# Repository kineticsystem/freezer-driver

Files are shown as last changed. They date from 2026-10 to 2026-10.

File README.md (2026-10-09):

# StepIt Freezer







## Table of Contents <!-- omit in toc -->

- [Introduction](#introduction)
- [Prerequisites](#prerequisites)
- [Install StepIt Freezer on the Microcontroller](#install-stepit-freezer-on-the-microcontroller)
  - [Connect the Arduino Nano](#connect-the-arduino-nano)
  - [Access the Serial Port](#access-the-serial-port)
  - [Flash the Firmware](#flash-the-firmware)
- [Install StepIt Freezer on the Local Computer](#install-stepit-freezer-on-the-local-computer)
  - [Check out the Submodules](#check-out-the-submodules)
  - [Pre-Commit Hooks](#pre-commit-hooks)
  - [Build the Project](#build-the-project)
- [Running the Application](#running-the-application)
  - [The Board Page](#the-board-page)
  - [Parameters](#parameters)
- [Troubleshooting](#troubleshooting)
- [How to run GitHub Actions locally](#how-to-run-github-actions-locally)

## Introduction

StepIt Freezer is a project to fire cameras and flashes from ROS2, through the Freezer board: an Arduino Nano driving two 74HC595 shift registers and 16 optocouplers, wired to 8 output jacks and 1 input jack.

- Fire up to 7 cameras and a flash at the same time, with the timing of each step kept by a hardware timer of the Nano.
- Load a sequence of steps once, each an output pattern and a hold time, and fire it with one short command, or with the remote trigger on IN1.
- Switch outputs on and off outside a shot, e.g. the lights, and stop a shot at any time.
- Watch the board in a web page: its outputs live, the commands, and the timing of every shot, against a fake controller or the real board.
- Talk to the Nano with a framed, CRC-checked protocol of one request and one response.

> [!WARNING]
> The project is being built. How it is built, and why, is in [ARCHITECTURE.md](docs/ARCHITECTURE.md); the ideas we weighed on the way are in [Brainstorming.md](Brainstorming.md). The firmware and the ROS2 side fire shots, tested on a Nano on its own; they have not yet driven cameras through the Freezer board.

## Prerequisites

To run StepIt Freezer, we need a computer with Ubuntu 24.04 and ROS2 Jazzy. Please refer to the document [Install ROS2 Jazzy on Ubuntu](https://docs.ros.org/en/jazzy/Installation/Ubuntu-Install-Debs.html).

StepIt Freezer runs with a fake controller by default, so we do not need the board to try it. For a real application, we need the following hardware.

- 1 x Freezer board, see its circuit, PCB and Gerber files in [docs/hardware](docs/hardware/README.md).
- 1 x [Arduino Nano 3.0](https://docs.arduino.cc/hardware/nano/), with the FTDI FT232R USB chip.
- 1 x USB cable, mini-B, that carries data, not only power.

## Install StepIt Freezer on the Microcontroller

This step is only required if you use a real hardware.

### Connect the Arduino Nano

Connect the Nano to the computer and check that Linux sees it. Run the following command, then plug the Nano in:

```
journalctl -kf
```

A working connection prints the following lines; the port is the last word, usually `ttyUSB0`.

```
usb 1-9: New USB device found, idVendor=0403, idProduct=6001, bcdDevice= 6.00
usb 1-9: Product: FT232R USB UART
usb 1-9: FTDI USB Serial Device converter now attached to ttyUSB0
```

If nothing is printed at all, see [Troubleshooting](#troubleshooting).

### Access the Serial Port

The port `/dev/ttyUSB0` belongs to the group `dialout`. To read and write it, without being root, you must add your user to that group:

```
sudo usermod -aG dialout $USER
```

The new group applies after we log out and log in again. To use the port straight away in the current session, grant our user access to it. The grant lasts until the Nano is unplugged.

```
sudo setfacl -m u:$USER:rw /dev/ttyUSB0
```

> [!IMPORTANT]
> A Nano clone with a CH340 USB chip, `idVendor=1a86`, is taken by `brltty`, the service for braille displays: its port appears and disappears at once. If you do not use a braille display, remove it with `sudo apt remove brltty`. A Nano with an FTDI chip is not affected.

No udev rule is required: the Nano is programmed over its serial port, which the group `dialout` already covers.

### Flash the Firmware

We develop the firmware with Visual Studio Code and the [PlatformIO](https://platformio.org) extension. Installing the Arduino IDE is not required.

The firmware, version 2.0.0, answers `Info`, `Echo`, `LoadSequence`, `Shoot`, `Status`, `SetOutputs` and `Stop`, and fires the loaded sequence when IN1 is pressed, unless a shot is running or no sequence is loaded. Timer1 runs the shot: each step starts at its own time, within about 5 µs, measured on the Nano. A step must last at least 40 µs: shorter steps fall behind, one after the other. The driver refuses a firmware of another major version, e.g. 1.1.0: flash the firmware of the same workspace.

To flash the microcontroller code into the Nano:

- Open VSCode
- Install the extension PlatformIO
- Open the subfolder `src/freezer_mcu` in VSCode
- Select the correct device and flash it

The same can be done from a terminal:

```
cd src/freezer_mcu
pio run --target upload --upload-port /dev/ttyUSB0
```

The project targets the board `nanoatmega328`, a Nano with the old bootloader, which listens at 57600 baud. A Nano with the newer Optiboot bootloader listens at 115200 baud: the upload then fails with `not in sync`, and the board in [`platformio.ini`](src/freezer_mcu/platformio.ini) must be `nanoatmega328new`.

The Nano resets every time the port is opened, and the firmware answers only once the bootloader has given up waiting for an upload: about 0.65 s on our Nano. StepIt Freezer waits for it, see `connect_delay` in [Brainstorming.md](Brainstorming.md).

Before the first upload to a Nano, save the firmware it already has, so that it can be written back. The folder `backup` is ignored by git: each machine keeps its own.

```
mkdir -p backup
avrdude -p atmega328p -c arduino -P /dev/ttyUSB0 -b 57600 -U flash:r:backup/nano-flash.hex:i -U eeprom:r:backup/nano-eeprom.hex:i
```

To write it back:

```
avrdude -p atmega328p -c arduino -P /dev/ttyUSB0 -b 57600 -U flash:w:backup/nano-flash.hex:i -U eeprom:w:backup/nano-eeprom.hex:i
```

PlatformIO installs `avrdude` in `~/.platformio/packages/tool-avrdude`; call it from there, with `-C ~/.platformio/packages/tool-avrdude/avrdude.conf`, if it is not on the `PATH`.

## Install StepIt Freezer on the Local Computer

### Check out the Submodules

The packages `framed_serial` and `serial` are git submodules, in `modules/framed-serial` and `modules/serial`. Clone the repository with its submodules:

```
git clone --recurse-submodules git@github.com:kineticsystem/stepit-freezer.git
```

If you missed the switch `--recurse-submodules`, fetch them with the following command:

```
git submodule update --init --recursive
```

Remember to enable recursion for relevant git commands, such that regular commands recurse into submodules by default.

```
git config --global submodule.recurse true
```

### Pre-Commit Hooks

Install the git pre-commit hooks, which format and check the code at every commit, with the following command:

```
pre-commit install
```

### Build the Project

The preferred way to build and run StepIt Freezer is to use a Docker container. It is defined in [`docker/docker-compose.yml`](docker/docker-compose.yml) and driven by the [`docker/dock.sh`](docker/dock.sh) script. See [docker/README.md](docker/README.md) for more details.

> [!IMPORTANT]
> The docker container provides a default user `developer` with password `developer`. That user may run `sudo` without being asked for it, so that the scripts in `bin` also work from a non-interactive shell, e.g.
> `docker exec stepit-freezer update.sh`.

Build the image and create the container. The script always mounts the repo it belongs to, so it can be called from anywhere:

```
./docker/dock.sh stepit-freezer build
```

Start the container with an interactive shell:

```
./docker/dock.sh stepit-freezer start
```

The container is privileged and mounts `/dev`, so the Nano on `/dev/ttyUSB0` is reachable from inside it. The commands below assume you are inside the container.

Install all required dependencies, including the packages of the board page.

```
update
```

Run Colcon to build the project, then build the board page into `web/dist`.

```
build
```

Execute all tests, those of the board page first.

```
test
```

The packages are the following.

| Package | Role |
|---|---|
| `freezer_msgs` | the `Shoot` action, the `Step`, `Outputs` and `Shot` messages, and the `SetOutputs` service |
| `freezer_driver` | the `Driver` interface, `DefaultDriver` over the serial port, `FakeDriver`, the sequence rules, the recipes, and `ShotRunner`, which runs one shot on a driver |
| `freezer_node` | the node `freezer`: the `Shoot` action server, the services `set_outputs` and `stop`, the topics `outputs` and `shots`, its parameters and its launch file |
| `framed_serial` | the framed serial protocol, in the submodule `modules/framed-serial`, from [framed-serial](https://github.com/kineticsystem/framed-serial) |
| `serial` | the serial port library, in the submodule `modules/serial`, from [serial](https://github.com/kineticsystem/serial), branch `ros2` |
| `freezer_mcu` | the PlatformIO project of the Nano, in `src/freezer_mcu`, not built by colcon |
| `web` | the board page, in React and TypeScript, built with Vite and pnpm, not built by colcon |

## Running the Application

By default, the node runs with a fake controller, so we do not need the board. Run the following commands to start StepIt Freezer:

```
source ~/ws/install/setup.bash
ros2 launch freezer_node freezer.launch.py
```

Open a different terminal, attach to the same container with `./docker/dock.sh stepit-freezer start`, and fire the default sequence:

```
ros2 action send_goal --feedback /freezer/shoot freezer_msgs/action/Shoot "{}"
```

The feedback says `state: 0` while the sequence is loaded into the controller, then `state: 1` with the shot id once the shot has started. The result comes when the controller reports the shot has ended, with the shot id and the time it started. A client can miss the first feedback: ROS2 drops the feedback published before the client has processed the acceptance of its goal. A client that needs to know a shot has started can rely on the result, not on the feedback.

To fire a sequence by name, give it in the goal:

```
ros2 action send_goal /freezer/shoot freezer_msgs/action/Shoot "{sequence: timed_light}"
```

To fire a raw table, for experiments, give its steps. Each step is a pattern of the 16 outputs and how long to hold it, in µs; the last step must switch every output off. This one focuses and opens the shutter of the camera on OUT1 for 100 ms:

```
ros2 action send_goal /freezer/shoot freezer_msgs/action/Shoot "{steps: [{outputs: 2, hold_us: 100000}, {outputs: 3, hold_us: 100000}, {outputs: 0, hold_us: 200000}]}"
```

A goal is rejected when no controller is connected, when a shot is running, or when its sequence breaks a rule of the controller. A rejection carries no reason in ROS2: the node logs it.

To switch outputs on outside a shot, e.g. lights on OUT8, give their pattern; they stay on until the next pattern, a shot, or a stop. A shot owns every output: while it runs, the outputs cannot be set, and it ends with every output off, lights included.

```
ros2 service call /freezer/set_outputs freezer_msgs/srv/SetOutputs "{outputs: 49152}"
ros2 service call /freezer/set_outputs freezer_msgs/srv/SetOutputs "{outputs: 0}"
```

To stop a shot where it is, and switch every output off, call `stop`. The goal of the shot aborts with the message `Stopped.`.

```
ros2 service call /freezer/stop std_srvs/srv/Trigger
```

Pressing the remote trigger, on IN1, fires the sequence loaded last, without the node; nothing is fired before the node has loaded one. A goal sent while that shot runs aborts: the controller is busy. The node sees that shot by polling the controller while it is idle, and tells it on `~/shots` like its own. With the fake controller, a service presses IN1:

```
ros2 service call /freezer/fake/press_trigger std_srvs/srv/Trigger
```

The node tells what the board does on two topics, which keep their last message for a client that subscribes late: `~/outputs`, the pattern of the outputs whenever it changes, and `~/shots`, each shot when it starts, with its steps, and when it ends.

```
ros2 topic echo /freezer/outputs
ros2 topic echo /freezer/shots
```

A third topic, `~/status`, tells whether the node talks to the controller, and why not, e.g. `No Freezer controller.`. It keeps its last message too, and comes again every second, so that a client knows the node still runs:

```
ros2 topic echo /freezer/status --qos-durability transient_local
```

To use the Freezer board, set the launch argument `use_fake`:

```
ros2 launch freezer_node freezer.launch.py use_fake:=false usb_port:=/dev/ttyUSB0
```

The result of a shot reports `worst_lateness_us`, the latest a step started after its time, as the controller measured it. Measured with firmware 1.1.0, whose Timer1 code 2.0.0 keeps, it is about 5 µs.

### The Board Page

The launch file also serves the board page, on [http://localhost:8092](http://localhost:8092), and starts the rosbridge it talks to the node through, on port 9092. The page fires the commands, and draws the timing of each shot, a row per line, as a logic analyser does.

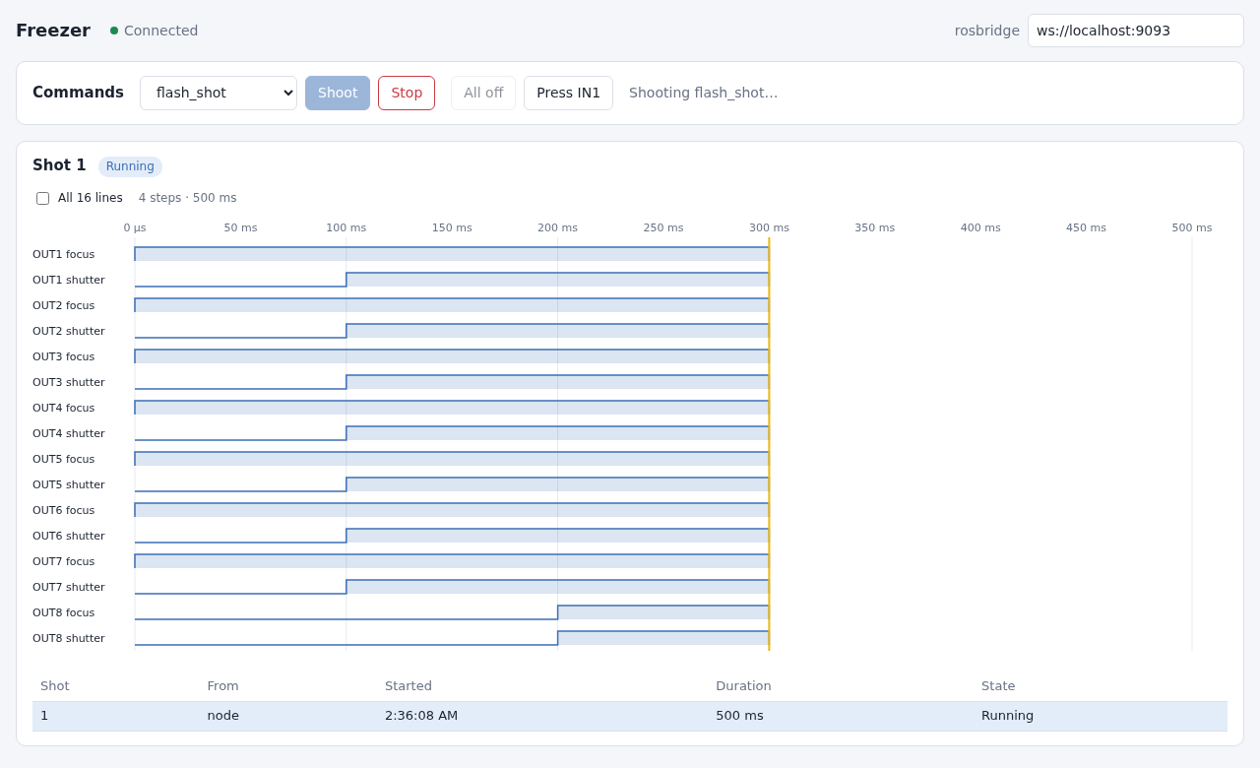
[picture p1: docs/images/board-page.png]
The board page during a shot


- **The commands.** Pick one of the node's sequences, listed as example 1, example 2 and so on, in the order of `sequence_names` with the default one first, and send it, stop a shot, switch every output on or off, or press IN1 of the fake controller. Press IN1 is disabled against the board, whose IN1 only a hand can press: close the jack, e.g. with the remote. All on closes every line of every jack until All off, a stop or a shot: a camera plugged in focuses and holds its shutter open meanwhile.
- **The lines and the latest shot.** A row per line of each jack, with an LED lit while the line is closed now, by a shot or by All on, as the node last told it, and the timing of the latest shot. During a shot, the LEDs follow its table at the cursor, so they always agree with the timing; a shot ends with every output off, so the LEDs of All on go out at the end of a shot. Before the first shot, the rows show all 16 lines and their LEDs only; with a shot, the lines it uses and any line on. Of the latest shot, the page shows its timing, and why it failed if it did; a stopped shot is cut where it stopped. A page that opens shows the last shot the node told of. A shot whose end never reaches the page, e.g. after a lost connection, stops counting as running two seconds after its duration, so that the commands are not kept disabled. It is drawn from the shot's table, which the controller runs exactly: the times are the table's, to the microsecond, not those at which the messages reached the page. Hover over it to read the time and the step. A row is a line of a jack, named after the contact of the plug it closes, e.g. `OUT8 tip` and `OUT8 ring`: all jacks are alike, and only the sequence decides what each drives. For a camera, the ring is the focus and the tip the shutter; a flash or a light closes both.

`build` builds the page into `web/dist`; the launch file serves nothing until it is built. To run the page without them, set `web:=false`. To work on the page, with hot reload, run its development server on port 5175 next to the launched node:

```
cd ~/ws/web && pnpm dev
```

The page connects to `ws://<host>:9092`, where `<host>` is the machine that served it; another rosbridge can be set in the field at the top of the page.

### Parameters

The parameters are in [`config/freezer.yaml`](src/freezer_node/config/freezer.yaml). To change them without editing it, e.g. from a robot that runs the Freezer, give a parameter file of our own, with a section `freezer`, in the launch argument `params_file`: it is loaded after `freezer.yaml`. The launch arguments `use_fake` and `usb_port` are applied last, and win over both files.

```
ros2 launch freezer_node freezer.launch.py params_file:=/path/to/robot.yaml
```

| Parameter | Default | Description |
|---|---|---|
| `use_fake` | `true` | Use a fake controller instead of the board. |
| `usb_port` | `/dev/ttyUSB0` | Serial port of the Nano. |
| `baudrate` | `9600` | Speed of the serial port, the one of the firmware. |
| `timeout` | `0.2` | Seconds to wait for one answer of the controller. |
| `connect_delay` | `1.0` | Seconds to wait after opening the port: the Nano resets and its bootloader runs first. |
| `reconnect_period` | `2.0` | Seconds between two tries to connect while there is no controller: a Nano missing at start, or unplugged, is connected once it is plugged in. 0 tries once, at start. |
| `poll_period` | `0.01` | Seconds between two status queries during a shot. |
| `end_margin` | `0.1` | Seconds after the duration of a shot before the node gives up on it. |
| `watch_period` | `0.2` | Seconds between two status queries while no goal runs, to see the shots of the remote trigger. 0 stops the queries. |
| `default_sequence` | `flash_shot` | The sequence of a goal that names none. |
| `sequence_names` | `[flash_shot, timed_light]` | The sequences under `sequences`. A ROS2 node must declare a parameter before reading it, and these names tell it which to declare. |

Each sequence has a `recipe` and the parameters of that recipe, in milliseconds. They can be changed while the node runs, e.g. `ros2 param set /freezer sequences.flash_shot.flash_ms 50.0`; the node loads the changed sequence before its next shot.

| Recipe | Parameters | Steps |
|---|---|---|
| `flash` | `cameras`, `flashes`, `focus_ms`, `shutter_to_flash_ms`, `flash_ms`, `cooldown_ms` | focus, open the shutters, fire the flashes, release everything |
| `timed_light` | `cameras`, `lights`, `focus_ms`, `shutter_to_light_ms`, `light_ms`, `light_to_close_ms`, `cooldown_ms` | focus, open the shutters, lights on, lights off, release everything |

`cameras`, `flashes` and `lights` are jack numbers, 1 to 8. A camera jack closes the focus line first, then the shutter line; a flash or a light jack closes both lines.

## Troubleshooting

**Nothing is printed when the Nano is plugged in, but its power LED is on.** The computer does not see the Nano at all: the USB data lines do not reach it. The cable may carry power only, which is common with mini-B cables, or the USB socket or the FT232 chip of the Nano is broken. A Nano mounted on the Freezer board can also take its power from the board, so its LED proves nothing about the USB side. Try a cable known to carry data, e.g. one used with a camera, plug it into a port of the computer and not a hub, and try the Nano on its own, off the board. If it still shows nothing, replace the Nano.

**Every shot is rejected, and the log says `Every shot is rejected until it answers` or `The Freezer controller stopped answering`.** The Nano is unplugged, or the computer did not see it, as a Raspberry Pi sometimes does at boot. Plug it in again: the node tries to connect every `reconnect_period`, 2 s, and logs `The Freezer controller is back`, with no restart. `/freezer/status` tells the error of the last try.

**`Permission denied` when opening `/dev/ttyUSB0`.** Our user is not in the group `dialout`, or we have not logged in again since joining it. See [Access the Serial Port](#access-the-serial-port).

**The port `/dev/ttyUSB0` appears and disappears at once.** The Nano is a clone with a CH340 chip and `brltty` takes it. See [Access the Serial Port](#access-the-serial-port).

**The log shows `Connection failed: SerialException: timeout.` once, then `Connection established`.** The Nano was still running its bootloader when the first `Info` arrived. The driver tries 5 times, 100 ms apart, so one or two timeouts are normal. If all 5 fail, raise `connect_delay`.

**Answers from the Nano arrive late, by up to 16 ms.** The FT232 holds received bytes until its latency timer expires, 16 ms by default. Lower it to 1 ms; it goes back to 16 ms when the Nano is plugged in again.

```
echo 1 | sudo tee /sys/bus/usb-serial/devices/ttyUSB0/latency_timer
```

## How to run GitHub Actions locally

At each push and pull request, the GitHub repository runs three workflows:

| Workflow | What it does |
|---|---|
| [`industrial_ci.yml`](.github/workflows/industrial_ci.yml) | builds the packages and runs their tests with [Industrial CI](https://github.com/ros-industrial/industrial_ci), in a container with Ubuntu 24.04 and ROS2 Jazzy |
| [`ci-format.yml`](.github/workflows/ci-format.yml) | runs the pre-commit hooks on every file, except the ament linters |
| [`ci-ros-lint.yml`](.github/workflows/ci-ros-lint.yml) | runs `ament_copyright`, `ament_lint_cmake` and `ament_cpplint` on `freezer_driver`, `freezer_msgs` and `freezer_node` |

The checkout of `industrial_ci` does not fetch the submodules: it builds `framed_serial` and `serial` from the repositories listed in [`freezer.repos`](freezer.repos). A new submodule must be added there too. The firmware, `freezer_mcu`, is not built by CI.

Sometimes, it may be desirable to execute the Continuous Integration pipeline locally. This is possible by using [Nektos](https://github.com/nektos/act).

Install the `act` command in the user folder `~/bin` as explained in the Nektos README.md file. The `.env` file at the root of the repository defines the global variables required by Industrial CI.

On its first run `act` asks interactively which runner image to use and aborts if it cannot prompt, so choose the image up front. Create `~/.config/act/actrc` with:

```
-P ubuntu-latest=catthehacker/ubuntu:act-latest
-P ubuntu-24.04=catthehacker/ubuntu:act-24.04
-P ubuntu-22.04=catthehacker/ubuntu:act-22.04
```

Then run any of the three workflows from the root of the repository:

```
~/bin/act pull_request --workflows ./.github/workflows/ci-format.yml    -s GITHUB_TOKEN=""
~/bin/act pull_request --workflows ./.github/workflows/ci-ros-lint.yml  -s GITHUB_TOKEN=""
~/bin/act pull_request --workflows ./.github/workflows/industrial_ci.yml -s GITHUB_TOKEN=""
```

The repository is public and `act` runs against the working tree rather than checking the code out, so no GitHub token is needed; the empty secret above stops `act` from prompting for one.

`industrial_ci` runs as a Docker action that mounts the workspace, so it does not honour `.gitignore`, and `rosdep` ends up scanning `build/` and `install/` too, and fails. The `build` script prevents this by dropping a `CATKIN_IGNORE` file into each of those directories, which is the marker `rosdep` looks for.

To check the format and the linters without `act`, run the same commands inside the container:

```
SKIP=ament_copyright,ament_lint_cmake,ament_cpplint pre-commit run --all-files --hook-stage manual
ament_copyright src/freezer_driver src/freezer_msgs src/freezer_node
```

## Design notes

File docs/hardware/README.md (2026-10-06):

# The Freezer Board

The drawings and the manufacturing files of the Freezer board, the circuit that StepIt Freezer controls: an Arduino Nano 3.0 driving two 74HC595 shift registers, whose 16 outputs drive 16 optocouplers, four LTV847, wired to 8 output jacks and 1 input jack.

Fritzing 1.0 opens the design, made with Fritzing 0.5, and warns that some of its parts are obsolete; they still show and connect as they did.

## Files

| File | What it is |
|---|---|
| [`CircuitSchema.png`](CircuitSchema.png) | The circuit: the Nano, the two 74HC595, the four LTV847 and their resistors. Its pin labels are wrong, see below. |
| [`FreezerPCB.svg`](FreezerPCB.svg), [`FreezerPCB.png`](FreezerPCB.png) | The PCB, as made: the jacks OUT1 to OUT8 and IN1 along the top edge, the optocouplers, the resistors, the shift registers and the Nano. |
| [`gerber`](gerber) | The Gerber files the PCB was made from: the contour, the copper and the solder mask of both sides, the bottom silkscreen and the drill file. |
| [`fritzing/Freezer.fzz`](fritzing/Freezer.fzz) | The source of the design, in [Fritzing](https://fritzing.org): the breadboard, schematic and PCB views from which the PCB images and the Gerber files were exported, on 31 July 2011. The file to open to change the board. |
| [`CameraLogic.png`](CameraLogic.png) | How a camera's remote release works: its focus and shutter lines are pulled up, and closing one to ground triggers it. An optocoupler of the board closes it like the camera's own button. |
| [`StereoPlug25mm.png`](StereoPlug25mm.png) | The 2.5 mm stereo plug of a camera's remote release: tip, ring and sleeve. |
| [`ArduinoNano30.png`](ArduinoNano30.png) | The pins of the Arduino Nano 3.0. |
| [`ShiftRegister595.png`](ShiftRegister595.png) | The pins of the 74HC595. |
| [`LTV847.png`](LTV847.png) | The pins of the LTV847, four optocouplers in one package. |

## The Wiring

Every output jack is the same: a stereo jack fed by two optocouplers, i.e. two lines, each closed against the sleeve. For jack k, bit 2(k-1) of the 16 outputs closes the shutter line, the tip, and bit 2(k-1)+1 the focus line, the ring. OUT8, which the default sequences use for the flash, is wired like the others: a flash sync is a single line, so a sequence closes both lines of a flash jack together, which fires it whether its cable uses the tip or the ring, and does nothing more with a mono plug, whose sleeve the ring touches.

| Nano pin | Use |
|---|---|
| D2 | `MR` of the 74HC595, low active |
| D3 | `SH_CP` of the 74HC595 |
| D4 | `DS` of the 74HC595 |
| D5 | `OE` of the 74HC595, low active |
| D6 | `ST_CP` of the 74HC595 |
| D7 | IN1, the remote trigger, pulled down by R2 |
| D8 | a second input, which the original firmware reads; no jack on the board |

> [!IMPORTANT]
> The pin labels of `CircuitSchema.png` do not match the PCB: e.g. the circuit draws `DS` on D2. The circuit predates the PCB by six weeks, and the PCB, the original firmware of the board and the firmware of this project agree on the table above, which is the truth.

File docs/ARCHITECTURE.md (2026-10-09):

# StepIt Freezer Architecture

## Table of Contents <!-- omit in toc -->

- [Introduction](#introduction)
- [The Big Picture](#the-big-picture)
- [The Packages](#the-packages)
- [The Board](#the-board)
- [The Protocol](#the-protocol)
  - [Commands](#commands)
  - [Errors](#errors)
  - [The Handshake and the Version](#the-handshake-and-the-version)
- [The Controller](#the-controller)
  - [States](#states)
  - [The Shot Owns the Outputs](#the-shot-owns-the-outputs)
  - [Running a Shot on Timer1](#running-a-shot-on-timer1)
  - [What the Controller Rejects](#what-the-controller-rejects)
- [The Remote Trigger](#the-remote-trigger)
- [The Host](#the-host)
  - [Driver](#driver)
  - [DefaultDriver](#defaultdriver)
  - [FakeDriver](#fakedriver)
  - [SynchronizedDriver](#synchronizeddriver)
  - [Sequence and the Recipes](#sequence-and-the-recipes)
  - [ShotRunner](#shotrunner)
  - [FreezerNode](#freezernode)
- [A Shot from the Host](#a-shot-from-the-host)
- [Stopping a Shot](#stopping-a-shot)
- [Losing the Controller](#losing-the-controller)
- [Seeing the Board](#seeing-the-board)
  - [What the Node Tells](#what-the-node-tells)
  - [The Board Page](#the-board-page)
- [Safety Nets](#safety-nets)
- [Tests](#tests)
- [Design Decisions and Trade-offs](#design-decisions-and-trade-offs)

## Introduction

This document explains how StepIt Freezer is built: the board, the protocol, the firmware of the Nano and the ROS2 side, what each part is responsible for, and why it is built that way. It describes the code as it is, firmware and protocol version 2.0.0. It assumes we have read the [README](../README.md). [Brainstorming.md](../Brainstorming.md) keeps the ideas we weighed on the way, including the ones we dropped.

It follows one rule: **once a shot starts, its timing belongs to the controller, and only a stop interrupts it**. The host loads a table of steps, asks for a shot and is told at once that it has started; the Nano walks the table on a hardware timer, whatever else happens on the serial port; the host polls until the controller says the shot has ended.

## The Big Picture

The Freezer board is an Arduino Nano driving two 74HC595 shift registers, whose 16 outputs drive 16 optocouplers, wired to 8 output jacks. An optocoupler only closes a switch: cameras, flashes and lights are powered by their own circuits, and the board closes their remote release, their sync or their power switch. A ninth jack, IN1, takes a remote trigger.

```mermaid
---
config:
  theme: base
  themeCSS: ".edgeLabel p { padding: 4px 10px; }"
  flowchart:
    padding: 20
    nodeSpacing: 40
    rankSpacing: 50
  class:
    padding: 16
  sequence:
    boxMargin: 12
    boxTextMargin: 8
    noteMargin: 28
    messageMargin: 40
    actorMargin: 60
    labelBoxWidth: 56
    labelBoxHeight: 28
  themeVariables:
    primaryColor: "#3b6fb6"
    primaryTextColor: "#ffffff"
    primaryBorderColor: "#2c5590"
    lineColor: "#8b949e"
    textColor: "#4d86d6"
    actorBkg: "#3b6fb6"
    actorBorder: "#2c5590"
    actorTextColor: "#ffffff"
    actorLineColor: "#8b949e"
    signalColor: "#8b949e"
    signalTextColor: "#4d86d6"
    noteBkgColor: "#3b6fb6"
    noteTextColor: "#ffffff"
    noteBorderColor: "#2c5590"
    secondaryColor: "#3b6fb6"
    tertiaryColor: "#3b6fb6"
    clusterBkg: "transparent"
    clusterBorder: "#8b949e"
    titleColor: "#4d86d6"
    edgeLabelBackground: "#3b6fb6"
    classText: "#ffffff"
    labelBoxBkgColor: "#3b6fb6"
    labelBoxBorderColor: "#2c5590"
    labelTextColor: "#ffffff"
    loopTextColor: "#4d86d6"
    mainBkg: "#3b6fb6"
    nodeBorder: "#2c5590"
    nodeTextColor: "#ffffff"
    secondaryBorderColor: "#2c5590"
    secondaryTextColor: "#ffffff"
    tertiaryBorderColor: "#2c5590"
    tertiaryTextColor: "#ffffff"
    errorBkgColor: "#3b6fb6"
    errorTextColor: "#ffffff"
---
flowchart TB
    Client["Clients<br/>a focus stacking sequence, ros2 CLI"] <-- "Shoot action<br/>set_outputs, stop" --> Node
    Page["Board page<br/>in a browser"] <-- "WebSocket, JSON" --> Bridge["rosbridge<br/>port 9092"]
    Bridge <-- "shots<br/>the commands" --> Node
    subgraph Host["freezer_node"]
        Node["FreezerNode"] --> Runner["ShotRunner<br/>its own thread"]
        Node --> Sync["SynchronizedDriver"]
        Runner --> Sync
        Sync --> Default["DefaultDriver"]
    end
    Default <-- "USB serial, 9600 baud<br/>framed, CRC-16" --> Nano
    subgraph Board["Freezer board"]
        Nano["Arduino Nano<br/>Timer1 walks the table"] -- "shift, latch" --> Registers["2 x 74HC595<br/>16 outputs"]
        Registers --> Opto["16 optocouplers"]
        Trigger["IN1"] --> Nano
    end
    Opto --> Jacks["OUT1 to OUT8"]
    Jacks --> Devices["cameras, flashes, lights<br/>powered externally"]
    Button["Remote trigger"] --> Trigger

    classDef default fill:#3b6fb6,stroke:#2c5590,color:#ffffff
```

The node's interface:

| Name | Type | What it does |
|---|---|---|
| `~/shoot` | `freezer_msgs/action/Shoot` action | Fire a shot: a sequence named in the parameters, or a raw table of steps. Feedback while it loads and runs; the result when the controller says it has ended. |
| `~/set_outputs` | `freezer_msgs/srv/SetOutputs` service | Latch a pattern on the 16 outputs outside a shot, e.g. the lights; it stays until the next pattern, a shot, or a stop. |
| `~/stop` | `std_srvs/srv/Trigger` service | End the running shot where it is, if any, and switch every output off. |
| `~/outputs` | `freezer_msgs/msg/Outputs` topic | The pattern of the outputs, whenever it changes. |
| `~/shots` | `freezer_msgs/msg/Shot` topic | Each shot when it starts, with its table and its start time, and when it ends, stops or fails. |
| `~/status` | `freezer_msgs/msg/ControllerStatus` topic | Whether the controller is connected, and why not, when it changes and every second. |
| `~/fake/press_trigger` | `std_srvs/srv/Trigger` service | With the fake controller only: press IN1. |
| `use_fake`, `usb_port`, `timeout`, ... | parameters | The connection, the polling and the sequences, see the [README](../README.md#parameters). |

## The Packages

| Package | Role |
|---|---|
| `freezer_msgs` | The `Shoot` action, the `Step`, `Outputs` and `Shot` messages, and the `SetOutputs` service. No code. |
| `freezer_driver` | The host side of the protocol, with no ROS interface: the `Driver` interface and its implementations, the sequence and its rules, the recipes, and `ShotRunner`. Its tests are in its `tests` folder. |
| `freezer_node` | The node `freezer`, its parameters and its launch file, which also starts the board page and its rosbridge, and its test. |
| `framed_serial`, `serial` | The framed serial protocol and the serial port, libraries in submodules under `modules`. |
| `freezer_mcu` | The firmware of the Nano, a PlatformIO project in `src/freezer_mcu`, not built by colcon. |
| `web` | The board page, in React and TypeScript, built with Vite and pnpm by the scripts in `bin`, not by colcon. |

`freezer_driver` knows nothing of ROS, apart from its logger, so that a shot can run and be tested on a fake controller and a fake clock, with no node and no time passing.

## The Board

The firmware drives the shift registers on port D: `MR` on D2, `SH_CP` on D3, `DS` on D4, `OE` on D5 and `ST_CP` on D6. IN1 is on D7, pulled down by R2. The circuit, the PCB and the Gerber files of the board are in [docs/hardware](hardware/README.md); the pin labels of the circuit are wrong, and the PCB and the firmware agree.

The 16 bits shift out least significant first, so bit 0 ends in the last stage of the chain. Each jack has two bits:

| Bits | Jack | Use |
|---|---|---|
| 0 and 1 | OUT1 | bit 0 the shutter line, the tip of the plug; bit 1 the focus line, its ring |
| 2 to 13 | OUT2 to OUT7 | the same layout, two bits a jack |
| 14 and 15 | OUT8 | the flash in the default sequences; a flash or a light jack closes both lines |
| - | IN1 | the remote trigger, on D7 |

The latch is what makes a step precise: all 16 outputs change together on the rising edge of `ST_CP`, however long the 16 bits took to shift in. The firmware shifts the next pattern in during the current step, and only latches it when the step ends.

## The Protocol

The host and the Nano speak the framed protocol of the `framed_serial` library: frames delimited by `0x7E`, escaped with `0x7D`, ending with a CRC-16, at 9600 baud. The first byte of a request is the command id; the first byte of a response is `0x11` for success or `0x12` for an error, followed by a reason. Numbers are most significant byte first. It is strictly one request, one response: the controller never speaks first, so a frame the host did not ask for can never be mistaken for the answer to its next request.

### Commands

| Id | Command | Request payload | Success payload |
|---|---|---|---|
| `0x76` | `Info` | none | version, limits and the name `FREEZER`, see [The Handshake](#the-handshake-and-the-version) |
| `0x79` | `Echo` | anything | the same bytes |
| `0x7B` | `LoadSequence` | step count, 1 byte; per step: type, 1 byte; outputs, 2 bytes; hold, 4 bytes in µs | duration, 4 bytes in µs |
| `0x7C` | `Shoot` | none | shot id, 2 bytes; duration, 4 bytes in µs |
| `0x75` | `Status` | none | state, 1 byte, 0 idle or 1 running; last shot id, 2 bytes; step, 1 byte; elapsed, 4 bytes in µs; worst lateness of the last shot, 4 bytes in µs |
| `0x77` | `SetOutputs` | outputs, 2 bytes | none |
| `0x78` | `Stop` | none | none |

- **A step** is a type, `0x00` "set and hold", the only one; the 16 outputs; and how long to hold them. 16 steps make a request of 114 bytes, under the 200 bytes of the receive buffer.
- **The shot id** counts from 1 after every reset, wraps back to 1 after `0xFFFF`, and is 0 when no shot has run since the reset. A shot fired by IN1 takes an id too.
- **A shot is over** for the host when the state is idle and the last shot id is the one `Shoot` returned.

### Errors

| Reason | When |
|---|---|
| `0x01` malformed | an unknown command id, or a payload of the wrong length |
| `0x02` invalid table | the table breaks a rule of [What the Controller Rejects](#what-the-controller-rejects) |
| `0x03` busy | `LoadSequence`, `Shoot` or `SetOutputs` while a shot runs |
| `0x04` no table | `Shoot` before any table is loaded |

### The Handshake and the Version

The path of a serial port does not tell what is plugged in, so `DefaultDriver::connect()` sends `Info` and checks the answer:

| Field | Size |
|---|---|
| status | 1 byte, `0x11` |
| version | 3 bytes: major, minor and patch |
| maximum steps | 1 byte, 16 |
| minimum hold | 4 bytes, 40 µs |
| maximum duration | 4 bytes, 10 s |
| name | the remaining bytes, in ASCII: `FREEZER` |

The driver accepts the controller only when the name is `FREEZER`, not another device on the wrong port, and its major version is the one the driver speaks, 2. The major version changes whenever the bytes on the wire change, so a driver never reads a controller it does not understand: flash the firmware of the same workspace. The node keeps the limits, and checks every table against them before sending it.

**The Nano resets when the port opens.** The DTR line of its FT232 resets it, and its bootloader listens for an upload for about 0.65 s before the firmware starts, losing any frame sent meanwhile. The driver waits `connect_delay`, 1 s, after opening the port, then tries `Info` up to 5 times, 100 ms apart. The node keeps the port open as long as the controller answers, because every reopen restarts the controller, which forgets its table and switches its outputs off.

## The Controller

The firmware, in `src/freezer_mcu`, is plain Arduino code with three parts:

| File | Role |
|---|---|
| `main.cpp` | The pins, the commands, the checks of a table, and the remote trigger. `loop()` serves the serial port and reads IN1. |
| `Sequencer.cpp` | The loaded table and the shot: Timer1, its interrupts, and the direct port writes to the shift registers. |
| `SerialPort.cpp`, `DataBuffer.cpp`, `CrcUtils.cpp` | The framed protocol, the firmware side of `framed_serial`. |

It uses 857 of the 2048 bytes of RAM of the Nano.

### States

```mermaid
---
config:
  theme: base
  themeCSS: ".edgeLabel p { padding: 4px 10px; }"
  flowchart:
    padding: 20
    nodeSpacing: 40
    rankSpacing: 50
  class:
    padding: 16
  sequence:
    boxMargin: 12
    boxTextMargin: 8
    noteMargin: 28
    messageMargin: 40
    actorMargin: 60
    labelBoxWidth: 56
    labelBoxHeight: 28
  themeVariables:
    primaryColor: "#3b6fb6"
    primaryTextColor: "#ffffff"
    primaryBorderColor: "#2c5590"
    lineColor: "#8b949e"
    textColor: "#4d86d6"
    actorBkg: "#3b6fb6"
    actorBorder: "#2c5590"
    actorTextColor: "#ffffff"
    actorLineColor: "#8b949e"
    signalColor: "#8b949e"
    signalTextColor: "#4d86d6"
    noteBkgColor: "#3b6fb6"
    noteTextColor: "#ffffff"
    noteBorderColor: "#2c5590"
    secondaryColor: "#3b6fb6"
    tertiaryColor: "#3b6fb6"
    clusterBkg: "transparent"
    clusterBorder: "#8b949e"
    titleColor: "#4d86d6"
    edgeLabelBackground: "#3b6fb6"
    classText: "#ffffff"
    labelBoxBkgColor: "#3b6fb6"
    labelBoxBorderColor: "#2c5590"
    labelTextColor: "#ffffff"
    loopTextColor: "#4d86d6"
    mainBkg: "#3b6fb6"
    nodeBorder: "#2c5590"
    nodeTextColor: "#ffffff"
    secondaryBorderColor: "#2c5590"
    secondaryTextColor: "#ffffff"
    tertiaryBorderColor: "#2c5590"
    tertiaryTextColor: "#ffffff"
    errorBkgColor: "#3b6fb6"
    errorTextColor: "#ffffff"
---
flowchart LR
    Boot(["Power on, reset,<br/>port opened"]) -- "outputs off" --> Empty["Idle, no table"]
    Empty -- "LoadSequence" --> Loaded["Idle, table loaded"]
    Loaded -- "Shoot, IN1" --> Running["Running<br/>Timer1 owns the outputs"]
    Running -- "end of the last step,<br/>Stop: outputs off" --> Loaded

    classDef default fill:#3b6fb6,stroke:#2c5590,color:#ffffff
```

`SetOutputs`, `Stop` and another `LoadSequence` leave an idle controller in its state. What each command gets, by state:

| Command | Idle, no table | Idle, table loaded | Running |
|---|---|---|---|
| `Info`, `Echo`, `Status` | answered | answered | answered |
| `LoadSequence` | loads | replaces the table | busy |
| `Shoot` | no table | fires | busy |
| `SetOutputs` | latches | latches | busy |
| `Stop` | outputs off | outputs off | ends the shot, outputs off |
| IN1 pressed | ignored | fires | ignored |

The controller keeps no other state: there is no "armed" flag, no watchdog, and the table is not stored in the EEPROM. A reset, including the one when the port opens, brings it back to the first state.

### The Shot Owns the Outputs

Outside a shot, `SetOutputs` latches a pattern, e.g. lights on OUT8, `0xC000`, which stays until the next one. During a shot, the shot writes all 16 outputs, and nothing else may touch them: `SetOutputs` is answered busy, and only `Stop` ends the shot. A shot ends with every output off, lights included, because its last step must be `0x0000`; a host that wants the lights back sends `SetOutputs` again. A shot that needs light has the bits of the light in its steps, timed by Timer1 like the rest, as the `timed_light` recipe does.

### Running a Shot on Timer1

Timer1, the 16-bit timer, counts ticks of 0.5 µs, at a prescaler of 8 on the 16 MHz Nano; its overflow interrupt extends it to 32 bits, which wrap after about 35 minutes. The compare-match interrupt fires at the end of each step:

```mermaid
---
config:
  theme: base
  themeCSS: ".edgeLabel p { padding: 4px 10px; }"
  flowchart:
    padding: 20
    nodeSpacing: 40
    rankSpacing: 50
  class:
    padding: 16
  sequence:
    boxMargin: 12
    boxTextMargin: 8
    noteMargin: 28
    messageMargin: 40
    actorMargin: 60
    labelBoxWidth: 56
    labelBoxHeight: 28
  themeVariables:
    primaryColor: "#3b6fb6"
    primaryTextColor: "#ffffff"
    primaryBorderColor: "#2c5590"
    lineColor: "#8b949e"
    textColor: "#4d86d6"
    actorBkg: "#3b6fb6"
    actorBorder: "#2c5590"
    actorTextColor: "#ffffff"
    actorLineColor: "#8b949e"
    signalColor: "#8b949e"
    signalTextColor: "#4d86d6"
    noteBkgColor: "#3b6fb6"
    noteTextColor: "#ffffff"
    noteBorderColor: "#2c5590"
    secondaryColor: "#3b6fb6"
    tertiaryColor: "#3b6fb6"
    clusterBkg: "transparent"
    clusterBorder: "#8b949e"
    titleColor: "#4d86d6"
    edgeLabelBackground: "#3b6fb6"
    classText: "#ffffff"
    labelBoxBkgColor: "#3b6fb6"
    labelBoxBorderColor: "#2c5590"
    labelTextColor: "#ffffff"
    loopTextColor: "#4d86d6"
    mainBkg: "#3b6fb6"
    nodeBorder: "#2c5590"
    nodeTextColor: "#ffffff"
    secondaryBorderColor: "#2c5590"
    secondaryTextColor: "#ffffff"
    tertiaryBorderColor: "#2c5590"
    tertiaryTextColor: "#ffffff"
    errorBkgColor: "#3b6fb6"
    errorTextColor: "#ffffff"
---
flowchart TB
    Shoot["Shoot or IN1"] --> First["Shift in step 0, latch it<br/>shift in step 1"]
    First --> Arm["Set the compare match<br/>for the end of step 0"]
    Arm --> ISR["Compare-match interrupt"]
    ISR --> Due{"Is the end of<br/>the step due?"}
    Due -- "no, a match of<br/>an earlier wrap" --> Wait["Wait for the next match"] --> ISR
    Due -- yes --> Last{"Last step?"}
    Last -- no --> Latch["Latch the shifted pattern<br/>record the lateness"]
    Latch --> Next["Shift in the pattern after it<br/>set the next compare value"] --> Due
    Last -- yes --> Done["Stop the interrupt, idle<br/>the last step switched every output off"]

    classDef default fill:#3b6fb6,stroke:#2c5590,color:#ffffff
```

- **Every step starts at its own time,** computed from the start of the shot, not from the end of the previous step: a late step does not delay the next ones.
- **The interrupt only latches.** The next pattern is already in the shift stage, so the outputs change at the interrupt, within a few microseconds. Shifting the next pattern in, with direct port writes, takes the rest: about 27.5 µs per step in all, measured on the Nano. A step must therefore last at least 40 µs; shorter ones would fall behind, one after the other.
- **The interrupt measures itself.** It records the worst lateness of the shot, how late a step boundary came after its time, which `Status` returns and the result of the action reports: about 5 µs on our Nano.
- **`loop()` stays free.** The serial port is served during the shot, which is what lets the host poll and stop it. The UART and `millis()` interrupts can delay a step by a few microseconds, which does not add up from step to step, and is three orders of magnitude below the shutter lag of a camera.
- **Shared state is read atomically.** `Status` copies the state of the shot with interrupts disabled for a few microseconds, so that no 16- or 32-bit value is read half-updated on the 8-bit microcontroller.

A step that is due before its compare match could be armed, e.g. a very short one, is handled by checking the time again after arming it, instead of waiting for the counter to wrap, 32.8 ms later.

### What the Controller Rejects

A generic table moves the responsibility for a safe shot from the firmware code to the table, so the controller checks the whole table before it keeps it:

- **a last step that is not `0x0000`.** A camera must never be left with its shutter held, nor a light left on, by a shot.
- **no step, or more than 16.**
- **a type other than "set and hold".**
- **a hold under 40 µs**, which Timer1 cannot keep.
- **a hold, or a total, over 10 s.**
- **a payload whose length does not match its step count.**

A rejected table changes nothing: the previous table stays loaded, and the outputs do not move. The host checks the same rules first, with `validate()` and the limits of the handshake, so that a goal with a bad table is rejected before any serial traffic.

## The Remote Trigger

IN1 fires the loaded table, exactly as `Shoot` would, unless a shot is running or no table is loaded. It is meant for testing, and it stays simple: no arming, no setting to disable it, nothing sent to the host. A shot it fires takes a shot id like any other, which `Status` returns, and a `Shoot` from the host meanwhile is answered busy. The node learns of it by polling, see [What the Node Tells](#what-the-node-tells).

`loop()` reads IN1 at every turn. A button bounces when pressed and when released, so a level counts only once it has held for 20 ms, and only a press fires: holding the button fires once, and the bounces of the release, which come after the shot, fire nothing.

After the port opens, the Nano has reset and holds no table, so IN1 does nothing until the node has loaded one, i.e. until its first shot.

## The Host

```mermaid
---
config:
  theme: base
  themeCSS: ".edgeLabel p { padding: 4px 10px; }"
  flowchart:
    padding: 20
    nodeSpacing: 40
    rankSpacing: 50
  class:
    padding: 16
  sequence:
    boxMargin: 12
    boxTextMargin: 8
    noteMargin: 28
    messageMargin: 40
    actorMargin: 60
    labelBoxWidth: 56
    labelBoxHeight: 28
  themeVariables:
    primaryColor: "#3b6fb6"
    primaryTextColor: "#ffffff"
    primaryBorderColor: "#2c5590"
    lineColor: "#8b949e"
    textColor: "#4d86d6"
    actorBkg: "#3b6fb6"
    actorBorder: "#2c5590"
    actorTextColor: "#ffffff"
    actorLineColor: "#8b949e"
    signalColor: "#8b949e"
    signalTextColor: "#4d86d6"
    noteBkgColor: "#3b6fb6"
    noteTextColor: "#ffffff"
    noteBorderColor: "#2c5590"
    secondaryColor: "#3b6fb6"
    tertiaryColor: "#3b6fb6"
    clusterBkg: "transparent"
    clusterBorder: "#8b949e"
    titleColor: "#4d86d6"
    edgeLabelBackground: "#3b6fb6"
    classText: "#ffffff"
    labelBoxBkgColor: "#3b6fb6"
    labelBoxBorderColor: "#2c5590"
    labelTextColor: "#ffffff"
    loopTextColor: "#4d86d6"
    mainBkg: "#3b6fb6"
    nodeBorder: "#2c5590"
    nodeTextColor: "#ffffff"
    secondaryBorderColor: "#2c5590"
    secondaryTextColor: "#ffffff"
    tertiaryBorderColor: "#2c5590"
    tertiaryTextColor: "#ffffff"
    errorBkgColor: "#3b6fb6"
    errorTextColor: "#ffffff"
---
classDiagram
    class Driver {
        <<interface>>
        connect() bool
        disconnect()
        get_info() InfoResponse
        load_sequence(sequence) LoadSequenceResponse
        shoot() ShootResponse
        set_outputs(outputs) Response
        stop() Response
        get_status() StatusResponse
    }
    Driver <|.. DefaultDriver
    Driver <|.. FakeDriver
    Driver <|.. SynchronizedDriver
    SynchronizedDriver o-- Driver : wraps
    DefaultDriver o-- FramedSerial : owns
    ShotRunner --> Driver : uses
    FreezerNode o-- SynchronizedDriver : owns
    FreezerNode o-- ShotRunner : owns
```

### Driver

`Driver` is the controller as the host sees it: one method per command, each sending one request and returning its one response, with the status and, for an error, its reason. A shot runs on the controller by itself: `shoot()` returns as soon as it has started, and the caller polls `get_status()`.

### DefaultDriver

The real controller, over a `FramedSerial`. It encodes the requests, decodes the responses, throws on a response it cannot read, e.g. a short one, and makes the handshake of [The Handshake](#the-handshake-and-the-version).

### FakeDriver

A controller in software, to run the node and test it without the board. It applies the rules of the firmware, runs a shot on a clock it is given, and records every pattern it latches, and when, in a timeline. Tests drive the clock by hand, so a shot of a second takes no time, and can make it fail in the ways that are hard to provoke on the board: a shot that never ends, a reset during a shot. `trigger()` presses IN1, and `set_plugged(false)` unplugs it: every call then throws, as on a port whose device is gone, until `set_plugged(true)` plugs it in again, afresh.

### SynchronizedDriver

The node calls the controller from two threads: the shot's thread polls it, and the services call it from the executor. `SynchronizedDriver` forwards each call to the driver it wraps, one at a time, so that a stop goes between two status queries, never in the middle of one, where it would mix the bytes of two frames on the port.

### Sequence and the Recipes

`Sequence` is a table of steps, its encoding for `LoadSequence`, and its duration. `validate()` checks it against the limits of the controller, with the rules of the firmware.

The recipes turn what a photographer thinks in, cameras, flashes and delays in milliseconds, into a table of patterns, so that the ROS2 interface never speaks in bits:

| Recipe | Parameters | Steps |
|---|---|---|
| `flash` | `cameras`, `flashes`, `focus_ms`, `shutter_to_flash_ms`, `flash_ms`, `cooldown_ms` | focus, open the shutters, fire the flashes, release everything |
| `timed_light` | `cameras`, `lights`, `focus_ms`, `shutter_to_light_ms`, `light_ms`, `light_to_close_ms`, `cooldown_ms` | focus, open the shutters, lights on, lights off, release everything |

A raw table can still be sent, in the goal, for experiments.

### ShotRunner

`ShotRunner` runs one shot on a driver, from loading its table to its end, with no ROS: time comes in as a clock and a sleep, so that a test runs a shot on the clock of a `FakeDriver`, instantly and exactly.

- **It loads only what changed.** The controller does not say which table it holds, so the runner remembers the sequence it loaded last, and loads a sequence only when it differs. It forgets it whenever the controller may have lost it.
- **It polls for the end.** It sleeps `poll_period`, 10 ms, between two status queries, reports the step and the elapsed time at each, and succeeds when the controller is idle with the shot's id.
- **It gives up on a shot that does not end** within its duration plus `end_margin`, 100 ms.
- **Callbacks** let its caller cancel the shot before it is fired, and learn when it has started and how it progresses.

### FreezerNode

The node checks a goal, then runs it on a thread of its own with a `ShotRunner`, turning the runner's callbacks into feedback, `LOADING` then `RUNNING` with the step and the elapsed time, and its result into the result of the goal. One goal runs at a time: a goal is rejected while another runs, when no controller is connected, or when its table breaks a rule of the limits, with no serial traffic. A goal can be canceled while its table loads, never once the shot has started.

While no goal runs, a timer queries the controller's status every `watch_period`, to see the shots of the remote trigger, and the node tells every shot and every change of the outputs on its topics, see [Seeing the Board](#seeing-the-board).

The controller can come and go, see [Losing the Controller](#losing-the-controller): while there is none, a thread of the node tries to connect every `reconnect_period`, and the node refuses every goal and every service meanwhile.

## A Shot from the Host

```mermaid
---
config:
  theme: base
  themeCSS: ".edgeLabel p { padding: 4px 10px; }"
  flowchart:
    padding: 20
    nodeSpacing: 40
    rankSpacing: 50
  class:
    padding: 16
  sequence:
    boxMargin: 12
    boxTextMargin: 8
    noteMargin: 28
    messageMargin: 40
    actorMargin: 60
    labelBoxWidth: 56
    labelBoxHeight: 28
  themeVariables:
    primaryColor: "#3b6fb6"
    primaryTextColor: "#ffffff"
    primaryBorderColor: "#2c5590"
    lineColor: "#8b949e"
    textColor: "#4d86d6"
    actorBkg: "#3b6fb6"
    actorBorder: "#2c5590"
    actorTextColor: "#ffffff"
    actorLineColor: "#8b949e"
    signalColor: "#8b949e"
    signalTextColor: "#4d86d6"
    noteBkgColor: "#3b6fb6"
    noteTextColor: "#ffffff"
    noteBorderColor: "#2c5590"
    secondaryColor: "#3b6fb6"
    tertiaryColor: "#3b6fb6"
    clusterBkg: "transparent"
    clusterBorder: "#8b949e"
    titleColor: "#4d86d6"
    edgeLabelBackground: "#3b6fb6"
    classText: "#ffffff"
    labelBoxBkgColor: "#3b6fb6"
    labelBoxBorderColor: "#2c5590"
    labelTextColor: "#ffffff"
    loopTextColor: "#4d86d6"
    mainBkg: "#3b6fb6"
    nodeBorder: "#2c5590"
    nodeTextColor: "#ffffff"
    secondaryBorderColor: "#2c5590"
    secondaryTextColor: "#ffffff"
    tertiaryBorderColor: "#2c5590"
    tertiaryTextColor: "#ffffff"
    errorBkgColor: "#3b6fb6"
    errorTextColor: "#ffffff"
---
sequenceDiagram
    participant Client
    participant Node as FreezerNode
    participant MCU as Nano firmware
    Client->>Node: goal, sequence flash_shot
    Note over Node: build the table, check the limits
    Node-->>Client: accepted
    Node-->>Client: feedback LOADING
    opt another table than the one loaded last
        Node->>MCU: LoadSequence
        MCU-->>Node: duration
    end
    Node->>MCU: Shoot
    Note over MCU: latch step 0, start Timer1
    MCU-->>Node: shot id, duration
    Node-->>Client: feedback RUNNING, shot id
    loop every poll_period
        Node->>MCU: Status
        MCU-->>Node: running, step, elapsed
        Node-->>Client: feedback step, elapsed
    end
    Node->>MCU: Status
    MCU-->>Node: idle, same shot id, worst lateness
    Node-->>Client: result, shot id, timings
```

The host learns the end of a shot late, by up to one polling period plus a status query, tens of milliseconds at 9600 baud, which is harmless when the cooldown alone is 200 ms. The controller, not the host's clock, decides when the shot has ended: the duration is only the host's deadline.

## Stopping a Shot

`Stop` ends a running shot where it is: the interrupt is switched off, zeros replace the next pattern in the shift stage, and are latched at once. The shot keeps its id, and the controller reads idle, exactly as after a shot that ran to its end, so the node remembers that it sent the stop and aborts the goal with the message `Stopped.`:

- **During the shot,** the stop goes to the controller between two status queries, and the next query reads idle.
- **Before the shot,** while its table loads, the node does not fire it, and the goal aborts with `Stopped before the shot started.`.
- **Between the two,** a stop that comes after the node decided to fire, and before `Shoot` reached the controller, found nothing to stop: the node sends `Stop` again as soon as the shot has started.

A stop with no goal running only switches the outputs off. A goal sent after the stop runs normally.

## Losing the Controller

The Nano resets when its power or its USB connection drops, and when the port is opened again. It then forgets its table and its shot ids, and switches its outputs off. The host notices it in two places:

- **`Shoot` answers "no table".** The runner forgets the table it loaded, loads it again, and fires once more. A second refusal aborts the goal.
- **A shot disappears.** The controller reads idle with another shot id than the one `Shoot` returned: the runner aborts the goal, saying the controller may have reset, and forgets its table, so the next shot loads it again.

A controller that never answers makes every call throw after `timeout`, and a shot that never ends aborts at its deadline.

**A controller unplugged is let go, and connected again when it is back.** While no goal runs, three status queries of `watch()` that fail in a row, 0.6 s, close the port: a Nano unplugged makes them all fail, a single failure on noise does not. A shot running when it goes fails as above, and the next queries close the port. Then, as when the Nano is missing at start, a thread of the node tries to connect every `reconnect_period`, 2 s: opening the port fails at once while the Nano is away, and the handshake succeeds once it is back. The Nano resets when its port opens, so the node tells every output off, and `watch()` sees its shot ids start again. The first failure goes to the log, not every try that follows. The thread connects apart from the executor, because a handshake takes more than a second, `connect_delay` and the tries of `Info`, and the services must answer meanwhile. On a Raspberry Pi, where the Nano is sometimes not seen at boot, it is enough to plug it in again: nothing needs a restart. `reconnect_period` 0 tries once, at start, and never lets the controller go.

## Seeing the Board

### What the Node Tells

Two topics tell what the board does. Each keeps its last message for a client that subscribes late (transient local), and only its last: rosbridge passes a new client the first message a topic kept, so with more, a page would open on the oldest.

- **`~/outputs`** is the pattern of the outputs whenever the node knows it changed: what `set_outputs` latched, all off after a stop and after a shot, and each step of a shot as the controller reports it when polled. A step shorter than the polling period may therefore never be published: this topic is for showing the board live, not for timing.
- **`~/shots`** tells each shot when it starts, with its table and the host time at which the controller confirmed its start, and when it ends, with how long it ran and its worst lateness, when it was stopped, or when it failed. The table and the start give the time of every step boundary to the microsecond, since the controller runs the table exactly; the time at which a message reaches a client gives it only to a few milliseconds.

**`~/status`** tells whether the node talks to the controller, with the serial port, or `fake`, and why not, e.g. `No Freezer controller.` or `The Freezer controller stopped answering: ...`. It is published when it changes, and again every second: a client that stops receiving it knows that the node is gone, which a latched message alone cannot tell, since it stays on a page after its node died. StepIt Macro shows it as an icon of its page.

The node only talks to the controller during its own shots, so it would never see one fired by IN1. While no goal runs, it queries the status every `watch_period`, 200 ms by default. A new shot id is a shot of the trigger: it runs the table the node loaded last, and the time the status says it has run gives its start. The node follows it to its end at the same period, and tells it on both topics, as `SOURCE_TRIGGER`. A shot shorter than the period is seen only once it ended, with its start estimated from its duration. A status taken while a goal starts is dropped, so that the goal's own shot is never taken for the trigger's.

With the fake controller, `~/fake/press_trigger` presses IN1 of the `FakeDriver`, under the lock of `SynchronizedDriver`, so that the trigger can be tried without the board.

### The Board Page

The board page, in `web`, fires the commands and draws the timing of each shot. It reaches the node through rosbridge, a WebSocket that speaks JSON, so that the browser needs no ROS: the launch file starts a rosbridge of its own, on port 9092, since a rosbridge only knows the messages installed next to it, and serves the built page with Python's HTTP server, on port 8092.

```mermaid
---
config:
  theme: base
  themeCSS: ".edgeLabel p { padding: 4px 10px; }"
  flowchart:
    padding: 20
    nodeSpacing: 40
    rankSpacing: 50
  class:
    padding: 16
  sequence:
    boxMargin: 12
    boxTextMargin: 8
    noteMargin: 28
    messageMargin: 40
    actorMargin: 60
    labelBoxWidth: 56
    labelBoxHeight: 28
  themeVariables:
    primaryColor: "#3b6fb6"
    primaryTextColor: "#ffffff"
    primaryBorderColor: "#2c5590"
    lineColor: "#8b949e"
    textColor: "#4d86d6"
    actorBkg: "#3b6fb6"
    actorBorder: "#2c5590"
    actorTextColor: "#ffffff"
    actorLineColor: "#8b949e"
    signalColor: "#8b949e"
    signalTextColor: "#4d86d6"
    noteBkgColor: "#3b6fb6"
    noteTextColor: "#ffffff"
    noteBorderColor: "#2c5590"
    secondaryColor: "#3b6fb6"
    tertiaryColor: "#3b6fb6"
    clusterBkg: "transparent"
    clusterBorder: "#8b949e"
    titleColor: "#4d86d6"
    edgeLabelBackground: "#3b6fb6"
    classText: "#ffffff"
    labelBoxBkgColor: "#3b6fb6"
    labelBoxBorderColor: "#2c5590"
    labelTextColor: "#ffffff"
    loopTextColor: "#4d86d6"
    mainBkg: "#3b6fb6"
    nodeBorder: "#2c5590"
    nodeTextColor: "#ffffff"
    secondaryBorderColor: "#2c5590"
    secondaryTextColor: "#ffffff"
    tertiaryBorderColor: "#2c5590"
    tertiaryTextColor: "#ffffff"
    errorBkgColor: "#3b6fb6"
    errorTextColor: "#ffffff"
---
flowchart LR
    subgraph Browser["The page"]
        Controls["Commands"]
        Shots["Shots<br/>timing diagram"]
        Store["Freezer<br/>the state, the commands"]
        Ros["Rosbridge<br/>WebSocket client"]
        Controls --> Store
        Shots --> Store
        Store --> Ros
    end
    Ros <-- "subscribe, call_service<br/>send_action_goal" --> Bridge["rosbridge"]
    Bridge <--> Node["freezer_node"]

    classDef default fill:#3b6fb6,stroke:#2c5590,color:#ffffff
```

| File | Role |
|---|---|
| `src/ros/rosbridge.ts` | The connection: topics, service calls and action goals over the rosbridge protocol. It reconnects by itself, and subscribes again after a reconnection. |
| `src/freezer/freezer.ts` | The node as the page sees it: a store of the outputs, from `~/outputs`, and of the last shots, from `~/shots`, and one method per command. It reads the parameter `use_fake` to tell whether `~/fake/press_trigger` exists, since the page has no rosapi to list the services. React reads it with `useSyncExternalStore`. |
| `src/freezer/board.ts` | The 16 lines and their bits, the rows of the timing diagram. |
| `src/freezer/timeline.ts` | When each line is on during a shot, from its table: the spans, the step at a time, the ticks of the axis. |
| `src/components` | The commands, and the timing diagram: a row per line, with its LED lit as `~/outputs` tells it, and the trace of the latest shot. |

The timing diagram is plain SVG: a row per line, high while it is closed, as a logic analyser draws it. The rows are named after the contacts of the plug, e.g. `OUT1 ring` and `OUT1 tip`, not after a device: the jacks are all alike, and only the sequence decides that one drives a camera, whose ring is its focus and tip its shutter, and another a flash. It draws the shot from its table, so it shows what the controller was told to do, to the microsecond, not a measurement of what it did; the worst lateness, which the controller measures, is in the result of the action and on `~/shots`. A running shot has a cursor, which advances on the page's own clock from the moment its start arrived, so that a host on another clock does not move it. A stopped shot is cut where it stopped. A shot whose end never reaches the page, e.g. after a lost connection, counts as running for its duration and 2 s more, `END_GRACE_MS`, and then no more: the page disables the commands while a shot runs, and must not keep them disabled forever.

## Safety Nets

- **A shot ends with every output off.** The controller and the host both refuse a table whose last step is not `0x0000`, so no shot leaves a shutter held or a light on.
- **A table is checked whole before anything changes.** A rejected table leaves the previous one loaded and the outputs as they were.
- **Outputs start off.** At power on and at reset, the firmware disables the outputs, clears the registers, latches the zeros, then enables them, so that whatever the 74HC595 held never reaches a camera.
- **A shot runs to its end, unless stopped.** Nothing else cuts it short: releasing a shutter mid-way leaves a camera in an unknown state, so the host's cancel only works before the shot starts. `Stop` is the deliberate exception.
- **The shot owns the outputs.** Nothing changes them while it runs, so a light switched by mistake cannot spoil an exposure.
- **The handshake refuses the wrong device and the wrong firmware,** by name and by major version.
- **A shot that never ends is abandoned** by the host after its duration plus `end_margin`.
- **IN1 is debounced,** so a press fires one shot.

What is deliberately not there:

- **No watchdog.** The controller does not act when the host goes silent; it keeps its outputs: a shot ends by itself, and what `SetOutputs` set, a light or even a camera bit, stays until it is changed, stopped, or the Nano resets. A node that restarts opens the port, which resets the Nano and switches every output off.
- **No checksum of the table.** `Shoot` fires whatever table is loaded; the host knows what it loaded.

## Tests

The tests run without the board: `DefaultDriver` against a mock of `FramedSerial`, everything else against `FakeDriver`.

| Test | What it covers |
|---|---|
| `test_default_driver` | The frames each command sends and how each response is read, the handshake, its retries and its refusals, the errors. |
| `test_fake_driver` | The fake runs a table, records its timeline, owns the outputs during a shot, stops, fires from IN1, fails when told to, and answers nothing while unplugged. |
| `test_sequence` | The encoding of a table and the rules of the controller. |
| `test_recipes` | Each recipe produces the expected table, and the jack to bit mapping. |
| `test_shot_runner` | A shot from load to end on a clock the test moves: the callbacks, a table loaded once, a cancel, a refused table, a shot that never ends, a reset during and between shots. |
| `test_freezer_node` | The ROS2 interface end to end: the action, its rejections, the services, a stop during a shot, a goal during a shot of IN1, the topics, the shots of the trigger the node sees while idle, and a controller missing at start or unplugged, connected again once it is back. |

The board page has tests of its own, with vitest, run by `bin/test.sh` and by the `Web` workflow of CI: the bits of the board, the timeline of a shot, how the shot messages make the list of shots, and the rosbridge client against a fake WebSocket.

The firmware has no automated test. The timing, the microseconds between latches, needs the board and a logic analyser or an oscilloscope on `ST_CP`; the rest, the commands, the states and IN1, is checked by hand on the Nano.

## Design Decisions and Trade-offs

**Timer1 runs the shot, not `delay()`.** The sketch the board came with chained `delay()` calls and `digitalWrite`s: each step changed a few hundred microseconds late, the error added up, and the controller was deaf for the whole shot. A compare-match interrupt that only latches a pattern shifted in ahead keeps every step within a few microseconds of its time, and leaves `loop()` free to answer the host. Disabling interrupts for the whole shot would make the timing perfect, but the controller could then neither answer nor stop, and a few microseconds of jitter are far below the jitter of a camera.

**The table is loaded, then fired.** A shot could carry its table, and since what matters is how precisely a shot runs, not how soon it starts, the few milliseconds of a bigger frame would not matter. We kept the load for IN1: a button has no table to send, so the controller must hold the one it fires. The loaded table is therefore the shot, whoever fires it, the host or the button. Loading once also means that a focus stack of 200 shots sends its table once.

**The host builds the table; the controller only replays it.** The firmware stays small, and a new kind of shot, e.g. a camera fired later than the others, needs no new firmware: the recipes on the host know the cameras, the flashes and the delays, and the controller only knows bits and microseconds.

**The host polls for the end of a shot.** `Shoot` answers at once with the duration, and the host polls `Status` every 10 ms until the shot has ended. It keeps the protocol to one request, one response, and the controller remains the authority on the end. A second answer sent by the controller at the end of the shot would tell the host about 10 ms sooner, but it breaks the pairing of requests and responses: telling the two answers apart takes sequence numbers, and recovering a lost one takes retransmissions, which can fire a shot twice.

**The shot owns the outputs, and only `Stop` interrupts it.** A shot is the reason the board exists, so nothing may change its outputs while it runs. Refusing `SetOutputs` with "busy", rather than ignoring it, tells the host that its outputs did not change, which a strict request and response protocol requires anyway.

**The node knows a shot was stopped; the controller does not say.** A stopped shot reads idle with its id, like one that ended. Only the node sends `Stop`, so it is the one place that knows, and the protocol needs no field for it.

**No checksum.** Version 1 had `LoadSequence` return the CRC-16 of the table, and `Shoot` send it back, so that the controller refused to fire a table the host did not mean. One host owns the port, so it only guarded against that host's own mistakes, which the runner avoids by remembering what it loaded. The CRC-16 of every frame, which checks the link, stays.

**No watchdog.** A watchdog matters where something left running is dangerous, e.g. a motor. Here a shot ends by itself, and outputs left on outside a shot are a choice of the host, which a restart of the node clears, since opening the port resets the Nano.

**IN1 stays simple.** It is for testing: arming it, disabling it while the host is connected or reporting its shots to the host would all be state to keep in step for a button. It fires the loaded table unless a shot runs, and the only thing it needs is a debounce, because a single press must fire a single shot.

**An action for the shot, services for the outputs and the stop.** A shot has a start, a progress and an end, which is what a ROS2 action is for: a client can move a rail, wait for it to settle, send a goal and wait for its result. Setting the outputs and stopping are immediate, so a service, which answers at once, fits them better. `ros2_control` does not fit: there is no joint and no control loop.

**A page to see the board, not RViz or PlotJuggler.** A URDF in RViz moves links from joint states, but their colours are fixed, so it cannot light a switch. PlotJuggler draws a timing diagram, but cannot fire a shot. A page can do both, looks like the board, and works the same against the fake controller and the real one. It draws the latest shot, whose timing shows what the outputs did, with an LED on each row showing the line as it is now, which also shows what no shot does, e.g. All on. During a shot, the LEDs show the shot's table at the cursor rather than `~/outputs`: the node learns each step when it polls the controller, at another moment than the cursor reaches it, and the two would disagree for a few milliseconds at each boundary, tens on the board.

**The timing diagram is drawn from the table.** Stamping each change when its message reaches the page would draw a 100 ms step as anything between 97 and 104 ms. The controller runs the table exactly, so the table and the confirmed start are the truth, to the microsecond; `~/outputs`, coarser, only lights the board.

**The node polls for the trigger, rather than the controller telling it.** The controller stays strictly request and response, and IN1 stays simple. A status query every 200 ms while idle costs little, and only matters for showing the trigger's shots.

**The Nano, at 9600 baud.** The board is designed for the footprint of the Nano, and its 2 KB of RAM are enough: the firmware uses 857 bytes. At 9600 baud, an `Info` round trip takes about 48 ms, and a status query tens of milliseconds, so the host polls a little slower than `poll_period` asks and learns the end of a shot a little later; the timing of the shot itself does not depend on the serial port at all.

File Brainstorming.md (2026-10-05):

# StepIt Freezer Brainstorming

## Table of Contents <!-- omit in toc -->

- [Introduction](#introduction)
- [Decisions](#decisions)
- [What We Start From](#what-we-start-from)
  - [The Freezer Board](#the-freezer-board)
  - [The Framed Protocol](#the-framed-protocol)
  - [The Old Firmware](#the-old-firmware)
- [The Shot](#the-shot)
  - [A Shot Is a Table of Steps](#a-shot-is-a-table-of-steps)
  - [Load, Then Trigger](#load-then-trigger)
  - [Lights, Stop and the Trigger](#lights-stop-and-the-trigger)
  - [Richer Steps](#richer-steps)
  - [What the Firmware Rejects](#what-the-firmware-rejects)
  - [Recipes on the Host](#recipes-on-the-host)
  - [Keeping the Critical Path Precise](#keeping-the-critical-path-precise)
  - [What the Controller Does While Shooting](#what-the-controller-does-while-shooting)
- [Telling the Host the Shot Has Ended](#telling-the-host-the-shot-has-ended)
  - [Idea 1: The Host Polls a Status Query](#idea-1-the-host-polls-a-status-query)
  - [Idea 2: The Acknowledgement Carries the Duration](#idea-2-the-acknowledgement-carries-the-duration)
  - [Idea 3: The Controller Sends an Event](#idea-3-the-controller-sends-an-event)
  - [Idea 4: The Next Response Carries the News](#idea-4-the-next-response-carries-the-news)
  - [Idea 5: The Camera Tells Us](#idea-5-the-camera-tells-us)
  - [Idea 6: Two Answers to One Request](#idea-6-two-answers-to-one-request)
  - [Is the Acknowledgement the Right Way?](#is-the-acknowledgement-the-right-way)
  - [Comparison](#comparison)
  - [Decision](#decision)
- [A First Draft of the Protocol](#a-first-draft-of-the-protocol)
  - [The Handshake](#the-handshake)
  - [A Shot from the Host](#a-shot-from-the-host)
- [The ROS2 Side](#the-ros2-side)
  - [An Action, Not a Service](#an-action-not-a-service)
  - [The Shoot Action](#the-shoot-action)
  - [The Node Parameters](#the-node-parameters)
  - [Shots the Node Did Not Ask For](#shots-the-node-did-not-ask-for)
  - [Packages](#packages)
- [Testing Without the Board](#testing-without-the-board)
  - [The Fake Driver](#the-fake-driver)
  - [The Tests](#the-tests)
  - [Testing the Firmware Logic](#testing-the-firmware-logic)
- [Seeing the Board](#seeing-the-board)
  - [What the Node Tells](#what-the-node-tells)
  - [The Board Page](#the-board-page)
  - [What It Cannot Show](#what-it-cannot-show)
- [Safety](#safety)
- [Open Questions](#open-questions)

## Introduction

StepIt Freezer lets ROS2 fire the Freezer board: up to 7 cameras and a flash, through the optocouplers driven by two 74HC595 shift registers on an Arduino Nano. It talks to the board with framed, CRC-checked request and response messages over the USB serial port.

This document collects ideas, and the decisions taken so far are listed in [Decisions](#decisions). The ROS2 packages and the firmware in `src` implement them, and fire shots on a Nano. See the [README](README.md) to build and run them. It follows one rule that everything else must respect: **once a shot starts, its timing belongs to the controller and nothing interrupts it**. The host asks for a shot and is told straight away that it has started, then polls until the controller says it has ended.

## Decisions

- **Timer1 runs the shot.** The table is walked by the Timer1 compare-match interrupt, with the next pattern shifted in ahead of time and latched on the interrupt. `loop()` stays free to answer the serial port during the shot, see [Keeping the Critical Path Precise](#keeping-the-critical-path-precise).
- **The host polls, Ideas 2 and 1.** `ShotResponse` returns at once with the shot id and the duration; the host waits that long and polls the status until the shot is done. The two-answer protocol of Idea 6 is not used.
- **The framed protocol, unchanged.** One request, one response, the framing and CRC-16 of `framed_serial`, no sequence number, no link-layer acknowledgement. The code is reused: `framed_serial` on the host, `SerialPort`, `DataBuffer`, `CrcUtils` and `Guard` in the firmware.
- **A table of steps, loaded, then fired.** `LoadSequence` sends the table, each step a 16-bit output bitmask and a hold time; `Shoot` fires the loaded table. See [A First Draft of the Protocol](#a-first-draft-of-the-protocol).
- **The shot owns the outputs; lights and stop beside it.** `SetOutputs` switches outputs on or off, e.g. the lights, outside a shot; `Stop` ends a shot at once. During a shot, every command that would move an output is answered "busy", except `Stop`. IN1 fires the loaded table, unless a shot runs or no table is loaded. See [Lights, Stop and the Trigger](#lights-stop-and-the-trigger).
- **No checksum of the table.** `Shoot` fires whatever table is loaded, and the host keeps track of what it loaded. One host owns the port, so the checksum only guarded against that host's own mistakes. Dropping it changes the wire, so it comes with version `2.0.0`, together with `SetOutputs` and `Stop`. See [A First Draft of the Protocol](#a-first-draft-of-the-protocol).
- **No watchdog.** The controller does not act when the host goes silent; it keeps its outputs as they are: a shot runs to its end and switches everything off by itself, and what `SetOutputs` set stays until it is changed, `Stop`, or a reset. Opening the port resets the Nano, so a host that restarts finds every output off. See [Safety](#safety).
- **A handshake and a version.** `connect()` sends `Info`; the controller answers with its version, major, minor and patch, and the name `FREEZER`. The driver refuses another name or another major version. See [The Handshake](#the-handshake).

## What We Start From

### The Freezer Board

The original sketch of the board fires a fixed sequence when input D7 goes high. The PCB maps the 16 shift register bits to the jacks as follows, bit 0 being the first one shifted out:

| Bits | Jack | Use |
|---|---|---|
| 0 and 1 | OUT1 | camera 1, even bit shutter, odd bit focus |
| 2 to 13 | OUT2 to OUT7 | cameras 2 to 7, same layout |
| 14 and 15 | OUT8 | flash |
| - | IN1 | remote trigger on D7, pull-down R2 |

The Arduino pins are D2 `MR`, D3 `SH_CP`, D4 `DS`, D5 `OE` and D6 `ST_CP`. The latch matters for timing: all 16 outputs change together on the rising edge of `ST_CP`, however long the 16 bits take to shift in. D8 and the J2 and J3 headers are free.

> [!IMPORTANT]
> The pin labels on [`docs/hardware/CircuitSchema.png`](docs/hardware/CircuitSchema.png) do not match the PCB. The PCB and `Freezer.h`, of the original sketch, agree, and they are the truth.

### The Framed Protocol

Two properties of the protocol of `framed_serial` shape the ideas below:

- **Strict request and response.** `DefaultDriver` writes a frame and blocks on `read()` for the answer. The firmware never speaks first. A frame the host did not ask for would be read as the answer to the next request.
- **Framing.** Frames are delimited by `0x7E`, escaped with `0x7D`, and end with a CRC-16, as the `framed_serial` package implements it. The first byte of a request is the command id, the first byte of a response is `0x11` (success) or `0x12` (error).

The firmware side, `SerialPort` and `DataBuffer`, is plain Arduino code with buffers of 200 bytes. It should fit the 2 KB of RAM of the Nano, but we must check it.

### The Old Firmware

An earlier firmware drove the Freezer board, together with two stepper motors, from one Nano, under a Qt client. Its shot runs this sequence on the same pins:

| Step | Pattern | Jacks | Hold |
|---|---|---|---|
| Pre-charge | `0x00AA` | focus on OUT1 to OUT4 | 100 ms |
| Open shutter | `0x00FF` | focus and shutter on OUT1 to OUT4 | 500 ms |
| Light on | `0xFFFF` | adds OUT5 to OUT8 | `flashTime`, 200 ms by default |
| Light off | `0x00FF` | OUT5 to OUT8 off | 200 ms |
| Close shutter | `0x0000` | all released | 200 ms |

Here the controller decides how long the subject is lit, so the precision of the `flashTime` step is the precision of the exposure.

Its protocol answers every request twice. Every frame starts with a sequence number. The firmware sends an acknowledgement, `[seq, 0x7F]`, as soon as a frame passes the CRC check, and the real response, `[seq, result]`, when the command has run. For the shot, `serial.flush()` pushes the acknowledgement out before the first output changes, so the acknowledgement means "started" and the response means "finished". The client resends a frame that is not acknowledged within 500 ms, up to 5 times, and matches the response to its request by the sequence number.

What we must not carry over:

- **The timing.** The shot is a chain of `delay()` calls, each step changes only after a `digitalWrite` shift of a few hundred microseconds, and the whole controller is deaf for about 1.2 s.
- **A retransmission fires a second shot.** When an acknowledgement is lost, the client resends the same frame and the firmware runs it again: nothing remembers the last sequence number.
- **The acknowledgement means "received", not "accepted".** It leaves before the command is decoded, so an unknown command is acknowledged and never answered, and the client, which has no timeout on the response, waits forever.
- **A typo.** `else if (cmd = SWITCH_LIGHT_CMD && ...)` assigns instead of comparing: any unknown command with a one-byte payload switches the lights.

## The Shot

### A Shot Is a Table of Steps

The sketch hard-codes four steps of 100, 100, 100 and 200 ms. A `ShootCommand` could carry the sequence instead, as a list of steps, each a 16-bit output pattern and how long to hold it:

| Step | Pattern | Hold |
|---|---|---|
| Focus | odd bits of the selected cameras | `focus_us` |
| Shutter | both bits of the selected cameras | `shutter_to_flash_us` |
| Flash | the same, plus bits 14 and 15 | `flash_us` |
| Release | `0x0000` | `cooldown_us` |

The host builds the table from parameters it understands, cameras and delays, and the controller only replays it. This keeps the firmware small and lets us change the sequence, e.g. a second flash or a camera fired later than the others, without flashing new firmware. At 7 bytes a step, 16 steps fit in one frame, see [A First Draft of the Protocol](#a-first-draft-of-the-protocol).

Both sequences we already have are tables: the flash shot of the Freezer sketch and the timed light of the old firmware differ only in their rows.

A simpler alternative is a fixed sequence with four durations and a camera mask. It is enough for today's use, and the protocol can grow into the table later.

### Load, Then Trigger

The table can travel in its own command instead of inside the shot. A `LoadSequence` command sends the table once; the firmware validates it and keeps it. A `Shoot` command of a single byte fires the stored table.

- **The shot starts sooner.** The frame that starts it is short, and the validation has already happened.
- **The same table is fired many times.** A focus stack of 200 shots sends the table once.
- **The remote trigger can use it.** IN1 can fire the stored table, so the button and ROS2 shoot the same way.

The price is state in the controller: the host must know which table is loaded. It remembers the last table it loaded, and forgets it when it connects, since the Nano resets when the port opens, and when the controller answers "no table". A checksum of the table, returned by `LoadSequence` and sent back by `Shoot`, would let the controller refuse a table the host did not mean; we dropped it, see [Decisions](#decisions).

### Lights, Stop and the Trigger

Besides the shot, we want to switch the lights on and off, stop whatever runs, and test the cameras. The lights, like the cameras, are powered by circuits of their own: an optocoupler only closes their switch, so a light is one or two bits of the 16, like a camera.

**Why not a table sent with the command.** Since what is critical is how precisely the shot runs, not how soon it starts, we considered dropping `LoadSequence` for one command carrying its table, `Run(table)`: every use, the shot, a lights test, a camera test, would send its own table and leave no state behind. The few milliseconds the bigger frame takes are irrelevant, since Timer1 keeps the timing of the steps whichever way the table arrived. We kept the load instead, for IN1: a button has no table to send, so the controller must hold the one it fires. The loaded table is therefore **the shot**, whoever fires it, ROS2 or the button.

What changes nothing in the loaded table gets a command of its own:

| Action | How |
|---|---|
| Shoot from ROS2 | `Shoot`, as before |
| Shoot from IN1 | fires the loaded table, unless a shot runs or no table is loaded |
| Lights on or off | `SetOutputs`, a 16-bit mask that stays until changed; it leaves the loaded table alone |
| Stop | `Stop`, always accepted: ends a running shot, writes `0x0000` |
| Test the cameras | fire the shot; to test them one by one, load a test table, then the shot again |

The rules:

- **The shot owns all 16 outputs.** It is the priority: while it runs, `SetOutputs`, `LoadSequence` and `Shoot` are answered "busy", and only `Stop` can end it. The protocol is strict request and response, so the controller must answer something, and "busy" tells the host that its outputs did not change.
- **A shot ends with every output off,** lights included: a light set by `SetOutputs` before the shot is off after it. A shot that needs light has the light's bits in its steps, timed by Timer1 like the rest, as the timed light of the old firmware does. The host sends `SetOutputs` again after the shot to have the lights back.
- **IN1 is for testing,** and stays simple: no arming, no setting to disable it, nothing sent to the host. It fires the loaded table unless a shot is running or no table is loaded, which is the case after every connection, since the Nano resets when the port opens. A button bounces when pressed and when released, after a short shot too, so the firmware counts a level of IN1 only once it has held for 20 ms, and only a press fires. A shot fired by IN1 still takes a shot id, which the host reads with `Status` if it cares, see [Shots the Node Did Not Ask For](#shots-the-node-did-not-ask-for). A `Shoot` from the host during it is answered "busy".
- **On the ROS2 side,** the node offers `set_outputs`, a `freezer_msgs/SetOutputs` service, and `stop`, a `std_srvs/Trigger`. A stop aborts the goal of the running shot with `Stopped.`: the controller reads idle with the shot id, as after a shot that ran to its end, so the node alone knows. The services call the controller while the shot's thread polls it: `SynchronizedDriver` lets one call through at a time.
- **A strobe is dropped.** It needs a repeat step, or more than the 16 steps that fit, and a strobe that runs until stopped breaks the limit on the duration. It was only an example.

### Richer Steps

A step that only sets a pattern and waits is enough for the shots we know. Two more kinds of step open new ones:

| Step | What it does | Use |
|---|---|---|
| Set and hold | output a pattern, wait a fixed time | every shot |
| Repeat | run steps `i` to `j` again, `n` times | a strobe, several flashes in one exposure, a burst |
| Wait for input | wait for D7 or D8 to go high, with a timeout | fire the flash on the X-sync of a camera instead of after a fixed delay |

A wait for an input makes the duration of the shot unknown in advance. That is the trade-off: a table of fixed holds has a duration the host can compute, a table with a wait does not. It is one more reason to confirm the end of the shot and never rely on the prediction alone, see [Idea 2](#idea-2-the-acknowledgement-carries-the-duration).

We do not need the richer steps today. Reserving a step type byte in the table now lets us add them without changing the frame.

### What the Firmware Rejects

A generic table moves the responsibility for a safe shot from the firmware code to the table, so the firmware must check every table before keeping it. It rejects a table:

- **that does not end with `0x0000`.** A camera must never be left with its shutter held, and a light must never stay on.
- **with more steps than it can store**, e.g. 8 or 16, depending on the RAM left on the Nano.
- **longer in total than a limit**, e.g. 10 s, computed with the repeats unrolled and the waits counted at their timeout.
- **with a hold shorter than it can time**, 40 µs on the Nano: the interrupt, the latch and the shift of the next pattern take about 27.5 µs, measured, and shorter steps fall behind one after the other.
- **with a repeat that points outside the table or forward**, or nested repeats, if we do not support them.

A rejected table changes nothing: the previous table stays loaded and the outputs do not move.

### Recipes on the Host

The ROS2 interface should not speak in bit patterns. A small builder in `freezer_driver` turns named recipes into tables:

| Recipe | Parameters | Table |
|---|---|---|
| Flash shot | cameras, focus, shutter-to-flash, flash, cooldown | the Freezer sketch sequence |
| Timed light | cameras, focus, shutter-to-light, light time, light-to-close, cooldown | the sequence of the old firmware |
| Strobe | cameras, flash count, flash interval | a repeat around the flash step |

The recipes and their parameters live in the parameters of the node, and the action goal names one, see [The Shoot Action](#the-shoot-action). The builder knows the jack to bit mapping of the board. A raw table can still be sent for experiments.

### Keeping the Critical Path Precise

On the ATmega328P of the Nano, three things decide how precise a step boundary is:

- **Who keeps time.** `delay()` and `loop()` are not precise enough to trust. Timer1, the 16-bit timer, can fire a compare-match interrupt at each step boundary with a resolution of 0.5 µs at a prescaler of 8, and up to about 32 ms per period; longer steps count several periods.
- **How long a write takes.** The sketch calls `digitalWrite` about 70 times per write, a few hundred microseconds. Writing the port registers directly takes about 10 µs. Better still, the interrupt only pulses `ST_CP`: the next pattern is shifted in ahead of time, during the current step, and the latch makes it appear at the exact moment.
- **What else runs.** The UART receive and transmit interrupts and the `millis()` timer can delay the Timer1 interrupt by a few microseconds. That is two to three orders of magnitude below the shortest step, and below the jitter of a camera shutter, which is in the order of milliseconds.

The extreme alternative is to disable interrupts for the whole shot and count cycles. The timing is then perfect, but the UART loses any byte that arrives during the shot, `millis()` stops, and the controller cannot answer anything. We would need it only if a few microseconds of jitter mattered, and they do not.

```mermaid
---
config:
  theme: base
  themeCSS: ".edgeLabel p { padding: 4px 10px; }"
  flowchart:
    padding: 20
    nodeSpacing: 40
    rankSpacing: 50
  class:
    padding: 16
  sequence:
    boxMargin: 12
    boxTextMargin: 8
    noteMargin: 28
    messageMargin: 40
    actorMargin: 60
    labelBoxWidth: 56
    labelBoxHeight: 28
  themeVariables:
    primaryColor: "#3b6fb6"
    primaryTextColor: "#ffffff"
    primaryBorderColor: "#2c5590"
    lineColor: "#8b949e"
    textColor: "#4d86d6"
    actorBkg: "#3b6fb6"
    actorBorder: "#2c5590"
    actorTextColor: "#ffffff"
    actorLineColor: "#8b949e"
    signalColor: "#8b949e"
    signalTextColor: "#4d86d6"
    noteBkgColor: "#3b6fb6"
    noteTextColor: "#ffffff"
    noteBorderColor: "#2c5590"
    secondaryColor: "#3b6fb6"
    tertiaryColor: "#3b6fb6"
    clusterBkg: "transparent"
    clusterBorder: "#8b949e"
    titleColor: "#4d86d6"
    edgeLabelBackground: "#3b6fb6"
    classText: "#ffffff"
    labelBoxBkgColor: "#3b6fb6"
    labelBoxBorderColor: "#2c5590"
    labelTextColor: "#ffffff"
    loopTextColor: "#4d86d6"
    mainBkg: "#3b6fb6"
    nodeBorder: "#2c5590"
    nodeTextColor: "#ffffff"
    secondaryBorderColor: "#2c5590"
    secondaryTextColor: "#ffffff"
    tertiaryBorderColor: "#2c5590"
    tertiaryTextColor: "#ffffff"
    errorBkgColor: "#3b6fb6"
    errorTextColor: "#ffffff"
---
flowchart TB
    Command["ShootCommand<br/>step table"] --> Validate{"Valid and idle?"}
    Validate -- no --> Error["Error response"]
    Validate -- yes --> Load["Load the table<br/>shift in step 0"]
    Load --> Start["Start Timer1<br/>send ShotResponse"]
    Start --> ISR["Timer1 interrupt<br/>pulse ST_CP"]
    ISR --> Next["Shift in the next pattern<br/>set the next compare value"]
    Next --> Last{"Last step?"}
    Last -- no --> ISR
    Last -- yes --> Done["Stop Timer1<br/>record the result"]

    classDef default fill:#3b6fb6,stroke:#2c5590,color:#ffffff
```

### What the Controller Does While Shooting

With the timer driving the steps, `loop()` stays free and keeps serving the serial port during the shot. That gives the controller three choices for a request that arrives mid-shot:

- **Answer queries, refuse commands.** A status or info query is answered; a second `ShootCommand` gets a "busy" error. This is the choice that makes polling possible. `Stop` is the one command accepted, see [Lights, Stop and the Trigger](#lights-stop-and-the-trigger).
- **Answer nothing.** The host must not send during a shot. Simple, but the host then needs to know the duration, and the watchdog must be suspended.
- **Queue the next shot.** Useful for a burst, but it is a feature we do not need yet.

The ISR should also measure itself: the `micros()` at each step boundary, or at least the worst lateness, kept for the host to read. It costs a few bytes of RAM and turns "it should be precise" into a number we can check.

## Telling the Host the Shot Has Ended

### Idea 1: The Host Polls a Status Query

The controller keeps a shot state: idle, running or done, the shot id, the step it is on and the measured timings. A `ShotStatusQuery` returns it. The host polls until it reads "done" for its shot id.

```mermaid
---
config:
  theme: base
  themeCSS: ".edgeLabel p { padding: 4px 10px; }"
  flowchart:
    padding: 20
    nodeSpacing: 40
    rankSpacing: 50
  class:
    padding: 16
  sequence:
    boxMargin: 12
    boxTextMargin: 8
    noteMargin: 28
    messageMargin: 40
    actorMargin: 60
    labelBoxWidth: 56
    labelBoxHeight: 28
  themeVariables:
    primaryColor: "#3b6fb6"
    primaryTextColor: "#ffffff"
    primaryBorderColor: "#2c5590"
    lineColor: "#8b949e"
    textColor: "#4d86d6"
    actorBkg: "#3b6fb6"
    actorBorder: "#2c5590"
    actorTextColor: "#ffffff"
    actorLineColor: "#8b949e"
    signalColor: "#8b949e"
    signalTextColor: "#4d86d6"
    noteBkgColor: "#3b6fb6"
    noteTextColor: "#ffffff"
    noteBorderColor: "#2c5590"
    secondaryColor: "#3b6fb6"
    tertiaryColor: "#3b6fb6"
    clusterBkg: "transparent"
    clusterBorder: "#8b949e"
    titleColor: "#4d86d6"
    edgeLabelBackground: "#3b6fb6"
    classText: "#ffffff"
    labelBoxBkgColor: "#3b6fb6"
    labelBoxBorderColor: "#2c5590"
    labelTextColor: "#ffffff"
    loopTextColor: "#4d86d6"
    mainBkg: "#3b6fb6"
    nodeBorder: "#2c5590"
    nodeTextColor: "#ffffff"
    secondaryBorderColor: "#2c5590"
    secondaryTextColor: "#ffffff"
    tertiaryBorderColor: "#2c5590"
    tertiaryTextColor: "#ffffff"
    errorBkgColor: "#3b6fb6"
    errorTextColor: "#ffffff"
---
sequenceDiagram
    participant Driver as DefaultDriver
    participant MCU as Nano firmware
    participant ISR as Timer1 ISR
    Driver->>MCU: ShootCommand
    MCU->>ISR: start
    MCU-->>Driver: ShotResponse, shot id 7
    loop until done
        Driver->>MCU: ShotStatusQuery
        MCU-->>Driver: running, step 2
    end
    Note over ISR: last step ends
    Driver->>MCU: ShotStatusQuery
    MCU-->>Driver: done, shot id 7, timings
```

It keeps the protocol exactly as it is, and the polling doubles as the watchdog heartbeat. The price is latency, up to one polling period, and a few small frames during the shot, which the ISR barely notices.

### Idea 2: The Acknowledgement Carries the Duration

The `ShotResponse` returns the shot id and the total duration of the table. The host knows the end time without asking, sleeps until then, and sends one status query to confirm. It is Idea 1 with one poll instead of many, and it leaves the serial line silent during the shot.

The host already knows the duration, since it built the table, but having the controller say it confirms that both agree on what will happen.

**The known duration is a prediction, not a proof.** Three things blur it:

- **The clock of the Nano.** Depending on the board, the ATmega328P runs from a crystal, within about 50 ppm, or from a ceramic resonator, within about 0.5%: up to 6 ms on a shot of 1.2 s.
- **The USB latency.** The FT232 of the Nano 3.0 holds received bytes for up to 16 ms before passing them to the host, the default of its latency timer on Linux. The host does not know when the shot started to better than that. The timer can be lowered to 1 ms in `/sys/bus/usb-serial/devices/ttyUSB0/latency_timer`.
- **Failures.** A controller that reset in the middle of the shot is silent, exactly like one that finished on time.

So the predicted end is a deadline: the host waits until then, plus a margin, and then needs a confirmation, either the second answer of Idea 6 or one status query.

### Idea 3: The Controller Sends an Event

When the shot ends, the controller sends a `ShotFinished` frame on its own. The host learns the end within about a millisecond.

The price is in the host: the request and response pairing of `DefaultDriver` no longer holds. A reader thread must own the serial port, tell responses from events by a message type byte, deliver responses to whoever is waiting and events to a callback. The two can cross on the wire: the event can arrive while the host waits for the answer to a status query. This is the biggest change to the design, and it is only worth it if we need the end of a shot within a millisecond.

### Idea 4: The Next Response Carries the News

Every response gets a small header with the state of the last shot. The host learns the end from whatever it sends next, usually the watchdog heartbeat. It keeps the pairing, but mixes shot state into unrelated messages, and the latency is the heartbeat period.

### Idea 5: The Camera Tells Us

The real end of a shot is not the end of the table but the camera writing a picture. A camera driver that downloads every picture the camera takes, combined with this one in a node, could wait for the `ShotFinished` of Freezer and for the picture of each camera. This does not replace the other ideas, it adds a second check: a camera that did not fire shows up as a missing picture.

A hardware version of the same idea uses the free D8: the X-sync of one camera, from its hot shoe or PC socket, tells the controller when the shutter is fully open. The flash could even be fired by it instead of by a fixed delay.

### Idea 6: Two Answers to One Request

This is the protocol of the old firmware, with its faults fixed. A `ShootCommand` gets two answers carrying the same sequence number: a `ShotResponse` when the shot starts and a `ShotFinished` when it ends. Every other command keeps its single answer.

```mermaid
---
config:
  theme: base
  themeCSS: ".edgeLabel p { padding: 4px 10px; }"
  flowchart:
    padding: 20
    nodeSpacing: 40
    rankSpacing: 50
  class:
    padding: 16
  sequence:
    boxMargin: 12
    boxTextMargin: 8
    noteMargin: 28
    messageMargin: 40
    actorMargin: 60
    labelBoxWidth: 56
    labelBoxHeight: 28
  themeVariables:
    primaryColor: "#3b6fb6"
    primaryTextColor: "#ffffff"
    primaryBorderColor: "#2c5590"
    lineColor: "#8b949e"
    textColor: "#4d86d6"
    actorBkg: "#3b6fb6"
    actorBorder: "#2c5590"
    actorTextColor: "#ffffff"
    actorLineColor: "#8b949e"
    signalColor: "#8b949e"
    signalTextColor: "#4d86d6"
    noteBkgColor: "#3b6fb6"
    noteTextColor: "#ffffff"
    noteBorderColor: "#2c5590"
    secondaryColor: "#3b6fb6"
    tertiaryColor: "#3b6fb6"
    clusterBkg: "transparent"
    clusterBorder: "#8b949e"
    titleColor: "#4d86d6"
    edgeLabelBackground: "#3b6fb6"
    classText: "#ffffff"
    labelBoxBkgColor: "#3b6fb6"
    labelBoxBorderColor: "#2c5590"
    labelTextColor: "#ffffff"
    loopTextColor: "#4d86d6"
    mainBkg: "#3b6fb6"
    nodeBorder: "#2c5590"
    nodeTextColor: "#ffffff"
    secondaryBorderColor: "#2c5590"
    secondaryTextColor: "#ffffff"
    tertiaryBorderColor: "#2c5590"
    tertiaryTextColor: "#ffffff"
    errorBkgColor: "#3b6fb6"
    errorTextColor: "#ffffff"
---
sequenceDiagram
    participant Driver as DefaultDriver
    participant MCU as Nano firmware
    participant ISR as Timer1 ISR
    Driver->>MCU: ShootCommand, seq 7
    Note over MCU: validate the table
    MCU->>ISR: start
    MCU-->>Driver: ShotResponse, seq 7, duration
    Note over Driver: no request while waiting
    Note over ISR: last step ends
    ISR->>MCU: done
    MCU-->>Driver: ShotFinished, seq 7, timings
    alt nothing within duration plus margin
        Driver->>MCU: ShotStatusQuery
        MCU-->>Driver: done, seq 7, timings
    end
```

The rules that make it safe:

- **The first answer means "accepted and started".** The firmware sends it after validating the command and starting the timer, not when the frame arrives. A rejected command gets an error and no second answer.
- **A repeated sequence number is not run twice.** The firmware keeps the last sequence number and its answers. A frame that repeats it, because the host resent it, gets the cached answer back.
- **One request in flight.** Between the two answers the host sends nothing, so nothing else can be answered in between and the pairing stays simple: whatever arrives is about the shot.
- **The host has a deadline.** If `ShotFinished` is not there within the duration plus a margin, e.g. 100 ms, the host asks with a `ShotStatusQuery`, Idea 1, which also tells a lost frame from a controller that reset.

### Is the Acknowledgement the Right Way?

The old firmware acknowledged every frame in the link layer and answered in the command layer. That is two separate ideas, and only the second one is worth keeping.

**A link-layer acknowledgement for every frame is not worth it.** It protects against a frame lost on a USB serial link, which almost never happens, and the link is already checked by the CRC. It doubles the frames, and it brings retransmission, which is exactly what fired the second shot. `framed_serial` works without it: one request, one response, and a timeout. If a frame is lost, the timeout catches it, and the host can always ask the state.

**Two answers for the one command that takes time are worth it.** The second answer is what tells the host "finished" within a millisecond and with no traffic during the shot. It is not an unsolicited event: it answers a request the host made, carries its sequence number, and arrives when the host expects it.

What it costs, compared with polling:

- **The host read path changes for one command.** `DefaultDriver` today reads one frame per request. `shoot()` reads the first answer and returns; a second call, e.g. `wait_shot_finished(timeout)`, reads the second. Any other call between the two is an error.
- **The link is busy during the shot.** That cost the old firmware its motors, which lived on the same Nano and stopped for every shot. Freezer has its own controller now and nothing else to do, so it costs nothing here.
- **The watchdog is silent during the shot.** No heartbeat can be sent while waiting. That matches the rule that a shot always runs to the end; the watchdog applies again once `ShotFinished` is sent.
- **A lost `ShotFinished` needs a way back.** The status query of Idea 1 is that way back, so we build both.

Polling, Idea 1 and 2, avoids all of this at the price of traffic during the shot and up to one polling period of delay. Both are sound. The difference is whether we prefer one special command in the host or a polling loop.

### Comparison

| Idea | Latency of the end | Protocol change | Host change |
|---|---|---|---|
| 1, polling | one polling period, e.g. 10 ms | one query | a polling loop |
| 2, duration | one query after the end | one field | a timer |
| 3, event | about 1 ms | a message type | a reader thread |
| 4, piggy-back | the heartbeat period | a header on every response | small |
| 5, camera | seconds, after the download | none | a node that joins the two |
| 6, two answers | about 1 ms | a sequence number, a second answer for the shot | a second read for the shot |

### Decision

**Ideas 2 and 1.** The `ShotResponse` carries the shot id and the duration; the host waits that long, then polls the status every 10 ms until it reads "done". It keeps the framed protocol, its code and its tests as they are, the controller is the authority on whether the shot has ended, and the measured timings come back with the status.

The timer makes this possible: polling is served by `loop()`, and the Timer1 interrupt latches each pattern at its count whatever `loop()` is doing. A poll can delay a step only by the length of another interrupt, a few microseconds, and that delay does not add up from step to step. The rules that keep it so:

- **No long critical section in `loop()`.** Copying the shot state for a status answer uses the `Guard` flags of the firmware or an atomic block of a few microseconds. No library that disables interrupts for long, e.g. `SoftwareSerial`.
- **A short interrupt.** Latch, shift the next pattern with direct port writes, set the next compare value: about 27.5 µs in all, measured on the Nano. No serial, no `digitalWrite`, no floating point.
- **Safe reads of shared state.** A 16-bit or 32-bit value read by `loop()` can be torn by the interrupt on an 8-bit microcontroller, so it is read under a guard.

Learning the end of the shot late, by up to one polling period plus the USB latency, is harmless when the cooldown alone is 200 ms.

## A First Draft of the Protocol

The framing, the CRC-16 and the byte order, most significant byte first, are those of `framed_serial`. A response starts with `0x11` for success or `0x12` for an error. An error carries a reason byte after it, which a reader that only checks the first byte can ignore.

| Id | Command | Request payload | Success payload |
|---|---|---|---|
| `0x76` | `Info` | none | version, limits and the name `FREEZER`, see [The Handshake](#the-handshake) |
| `0x75` | `Status` | none | state, 1 byte; last shot id, 2 bytes; current step, 1 byte; elapsed, 4 bytes in µs; worst lateness of the last shot, 4 bytes in µs |
| `0x7B` | `LoadSequence` | step count, 1 byte; then per step: type, 1 byte; bitmask, 2 bytes; hold, 4 bytes in µs | total duration, 4 bytes in µs |
| `0x7C` | `Shoot` | none | shot id, 2 bytes; total duration, 4 bytes in µs |
| `0x79` | `Echo` | anything | the same bytes |
| `0x77` | `SetOutputs` | bitmask, 2 bytes | none |
| `0x78` | `Stop` | none | none |

- **Ids.** `Shoot` keeps the id it had in the old firmware. Another device on the wrong port that answers `Info` gives another name, and is refused.
- **The step.** Type `0x00` is "set and hold"; the other values are reserved for [Richer Steps](#richer-steps). The bitmask is the 16 outputs, bit 0 being OUT1 shutter, see [The Freezer Board](#the-freezer-board). A step is 7 bytes, and 16 steps make a payload of 114 bytes, 116 with the CRC, under the 200 bytes of the receive buffer, which keeps the bytes unescaped.
- **No checksum.** Version `1.1.0` had `LoadSequence` return the CRC-16 of the table, and `Shoot` send it back, so that the controller refused to fire a table other than the one the host meant: a test table the shot was not loaded again after, or a table whose `LoadSequence` answer was lost. `Status` returned it too. With one host on the port, these are mistakes of that host, which it avoids by remembering what it loaded, so version `2.0.0` drops the checksum from the three commands, and the error "wrong table" with it. The CRC-16 of every frame, which checks the link, stays.
- **`SetOutputs` and `Stop`.** `SetOutputs` writes its mask at once and keeps it until the next one, a shot, or `Stop`. `Stop` writes `0x0000` and, during a shot, stops Timer1: the shot ends where it was, and `Status` reads idle with its shot id. Added in `2.0.0`, with the removal of the checksum, which changes the wire.
- **The state.** `0x00` idle, `0x01` running. A shot is over for the host when the state is idle and the last shot id is the one `Shoot` returned.

| Error reason | When |
|---|---|
| `0x01` malformed | the payload has the wrong length or an unknown command id |
| `0x02` invalid table | the table breaks a rule of [What the Firmware Rejects](#what-the-firmware-rejects) |
| `0x03` busy | `LoadSequence`, `Shoot` or `SetOutputs` while a shot runs |
| `0x04` no table | `Shoot` before any table is loaded |

### The Handshake

The serial port path alone does not tell the driver what is attached, so `connect()` checks it. It sends `Info` and reads the answer, the limits before the name so that the name stays "the remaining bytes":

| Field | Size |
|---|---|
| status | 1 byte, `0x11` |
| version | 3 bytes: major, minor and patch |
| maximum steps | 1 byte |
| minimum hold | 4 bytes, in µs |
| maximum duration | 4 bytes, in µs |
| name | the remaining bytes, in ASCII: `FREEZER` |

The driver accepts the controller only when:

1. **The name is `FREEZER`.** Any other name, from another device on the wrong port, is refused at once, without more attempts: the device answered, it is the wrong one.
2. **The major version is the one the driver speaks.** Otherwise the driver refuses, logs both versions and says to flash the firmware that matches the workspace.

Then it logs the firmware version and keeps the limits, which the recipe builder and the `FakeDriver` use to reject a table before sending it.

**The version.** The firmware defines `VERSION_MAJOR`, `VERSION_MINOR` and `VERSION_PATCH`, the driver `kExpectedProtocolVersion`. The first version is `1.0.0`, which answers `Info` and `Echo`; `1.1.0` adds `LoadSequence`, `Shoot` and `Status`, a minor version since a driver of 1.0.0 knows nothing of them.

| Part | Changes when | Driver |
|---|---|---|
| major | the wire changes: a command id, a field, a size, a meaning | refuses another major |
| minor | something is added that an older driver can ignore, e.g. a new command | accepts, logs it |
| patch | a fix with no change on the wire | accepts, logs it |

The firmware and the driver live in the same repository, so a change of the wire changes both, and the major version, in the same commit.

**The Nano resets when the port opens.** Unlike a microcontroller with native USB, the Nano 3.0 is reset by the DTR line of the FT232 every time the host opens the port. The bootloader then listens for an upload before the firmware starts, and a frame sent in that time is lost. On our Nano, with the old bootloader, the first `Info` was answered 0.65 s after opening the port, at the 4th attempt. The driver's 5 attempts, 0.2 s of timeout and 100 ms apart, last about 1.5 s: enough for this Nano, with little margin, and not for a bootloader that waits longer. The driver waits after opening the port, a `connect_delay` parameter of 1 s by default, before its first `Info`. Keeping the port open for the whole session matters for the same reason: every reopen restarts the controller and clears the loaded table.

### A Shot from the Host

1. `LoadSequence` once, keep the duration, and remember the table as loaded.
2. `Shoot`, keep the shot id.
3. Wait for the duration.
4. `Status` every 10 ms until it is idle with that shot id, or fail after the duration plus 100 ms.

## The ROS2 Side

### An Action, Not a Service

A shot has a start, a duration and an end, which is what a ROS2 action is for. A client such as a focus stacking sequence can move a rail, wait for it to settle, send a goal, wait for the result, and move on.

`ros2_control` does not fit here: there is no joint and no control loop, only a command and its result. A plain node with an action server is simpler.

### The Shoot Action

The goal names a sequence defined in the parameters of the node, or carries a raw table. Most clients send a name, or nothing for the default sequence: the setup of the rig changes rarely, and a focus stack fires the same shot hundreds of times.

`freezer_msgs/action/Shoot.action`:

```
# Goal

# The name of a sequence in the node parameters. Empty for default_sequence.
# Ignored when steps is not empty.
string sequence

# A raw table, for experiments. When not empty, it is sent as it is.
freezer_msgs/Step[] steps

---

# Result

# Why the shot failed, empty on success.
string message

# The id the controller gave the shot.
uint16 shot_id

# Host time when the controller confirmed the start of the shot.
builtin_interfaces/Time started

# Duration of the table, as computed by the controller.
uint32 duration_us

# The latest a step boundary came after its time, as measured by the controller.
uint32 worst_lateness_us

---

# Feedback

uint8 LOADING = 0  # the table is being validated and loaded
uint8 RUNNING = 1  # the controller has started the shot
uint8 state

# Valid when RUNNING.
uint16 shot_id
uint32 duration_us
uint8 step
uint32 elapsed_us
```

`freezer_msgs/msg/Step.msg`:

```
# One step of a shot: output a pattern, then hold it.

uint8 SET_AND_HOLD = 0  # the other values are reserved for repeat and wait steps
uint8 type

# The 16 outputs, a bit per optocoupler: for jack k, bit 2(k-1) is the
# shutter and bit 2(k-1)+1 the focus.
uint16 OUT1_SHUTTER = 1
uint16 OUT1_FOCUS = 2
uint16 OUT2_SHUTTER = 4
uint16 OUT2_FOCUS = 8
# ... up to
uint16 OUT8_SHUTTER = 16384
uint16 OUT8_FOCUS = 32768
uint16 outputs

# How long to hold the pattern, in µs.
uint32 hold_us
```

The hold is a `uint32` in microseconds, not a `builtin_interfaces/Duration`: it is what the controller counts, and a client sees exactly what will run, with no rounding.

**The shot starts with the first `RUNNING` feedback.** That is the ROS2 side of the `ShotResponse`. The status of the goal cannot say it: a goal goes from accepted to executing to succeeded or aborted, and cannot be aborted before it executes, so the goal executes from the start and the feedback tells the two phases apart. The feedback is a hint, not a guarantee: ROS2 drops the feedback published before the client has processed the acceptance of its goal, so a fast shot can reach the client with no `LOADING` and without its first `RUNNING`. The result carries the shot id and the time the shot started, whatever feedback arrived.

**The rules of the server:**

| Callback | Does |
|---|---|
| `handle_goal` | rejects the goal when the driver is not connected, when a goal is already active, or when the table breaks a rule of the limits read at the handshake; accepts and executes it otherwise |
| `handle_cancel` | accepts while `LOADING`, rejects once `RUNNING`: a shot that has started always runs to the end |
| execution | hands the table to `ShotRunner`, which loads it when it differs from the table it loaded last, sends `Shoot`, and polls the status until the controller is idle with the shot id; publishes `RUNNING` and the progress as feedback, and succeeds, or aborts with a `message` on an error or a timeout |

A rejection carries no reason in ROS2, so the node logs it, and the rules are the ones `Info` reported, which a client can read too. Validating in `handle_goal` costs no serial traffic: the limits are known since the handshake.

One goal at a time keeps the controller simple, and the polling, the loading and the shot run on one thread that owns the driver.

```mermaid
---
config:
  theme: base
  themeCSS: ".edgeLabel p { padding: 4px 10px; }"
  flowchart:
    padding: 20
    nodeSpacing: 40
    rankSpacing: 50
  class:
    padding: 16
  sequence:
    boxMargin: 12
    boxTextMargin: 8
    noteMargin: 28
    messageMargin: 40
    actorMargin: 60
    labelBoxWidth: 56
    labelBoxHeight: 28
  themeVariables:
    primaryColor: "#3b6fb6"
    primaryTextColor: "#ffffff"
    primaryBorderColor: "#2c5590"
    lineColor: "#8b949e"
    textColor: "#4d86d6"
    actorBkg: "#3b6fb6"
    actorBorder: "#2c5590"
    actorTextColor: "#ffffff"
    actorLineColor: "#8b949e"
    signalColor: "#8b949e"
    signalTextColor: "#4d86d6"
    noteBkgColor: "#3b6fb6"
    noteTextColor: "#ffffff"
    noteBorderColor: "#2c5590"
    secondaryColor: "#3b6fb6"
    tertiaryColor: "#3b6fb6"
    clusterBkg: "transparent"
    clusterBorder: "#8b949e"
    titleColor: "#4d86d6"
    edgeLabelBackground: "#3b6fb6"
    classText: "#ffffff"
    labelBoxBkgColor: "#3b6fb6"
    labelBoxBorderColor: "#2c5590"
    labelTextColor: "#ffffff"
    loopTextColor: "#4d86d6"
    mainBkg: "#3b6fb6"
    nodeBorder: "#2c5590"
    nodeTextColor: "#ffffff"
    secondaryBorderColor: "#2c5590"
    secondaryTextColor: "#ffffff"
    tertiaryBorderColor: "#2c5590"
    tertiaryTextColor: "#ffffff"
    errorBkgColor: "#3b6fb6"
    errorTextColor: "#ffffff"
---
sequenceDiagram
    participant Client
    participant Node as FreezerNode
    participant MCU as Nano firmware
    Client->>Node: goal, sequence flash_shot
    Note over Node: build the table, check the limits
    Node-->>Client: accepted
    Node-->>Client: feedback LOADING
    opt another table is loaded
        Node->>MCU: LoadSequence
        MCU-->>Node: duration
    end
    Node->>MCU: Shoot
    MCU-->>Node: shot id, duration
    Node-->>Client: feedback RUNNING, shot id
    loop every 10 ms
        Node->>MCU: Status
        MCU-->>Node: running or idle
    end
    Node-->>Client: result, timings
```

### The Node Parameters

The sequences are parameters, so they are set in a YAML file and can be changed at runtime with `ros2 param set`; a changed sequence is loaded into the controller before its next shot.

```yaml
freezer:
  ros__parameters:
    use_fake: true
    usb_port: /dev/ttyUSB0
    baudrate: 9600
    timeout: 0.2          # s, for one answer
    connect_delay: 1.0    # s, the Nano resets when the port opens
    poll_period: 0.01     # s
    end_margin: 0.1       # s, after the duration, before giving up
    default_sequence: flash_shot
    sequence_names: [flash_shot, timed_light]
    sequences:
      flash_shot:
        recipe: flash
        cameras: [1, 2, 3, 4, 5, 6, 7]
        flashes: [8]
        focus_ms: 100.0
        shutter_to_flash_ms: 100.0
        flash_ms: 100.0
        cooldown_ms: 200.0
      timed_light:
        recipe: timed_light
        cameras: [1, 2, 3, 4]
        lights: [5, 6, 7, 8]
        focus_ms: 100.0
        shutter_to_light_ms: 500.0
        light_ms: 200.0
        light_to_close_ms: 200.0
        cooldown_ms: 200.0
```

`sequence_names` is there because a ROS2 node must declare a parameter before reading it, and the names tell it which `sequences.<name>.*` to declare. The durations are in milliseconds for people to read; the builder rounds them to microseconds.

With the node running, a shot from the command line:

```
ros2 action send_goal --feedback /freezer/shoot freezer_msgs/action/Shoot "{sequence: flash_shot}"
```

### Shots the Node Did Not Ask For

The IN1 button fires the loaded table without the node. When the node polls the status, a new shot id tells it that a shot happened. It could publish every shot, its own and the button's, on a `~/shots` topic, so that a node collecting pictures knows a shot was fired whoever fired it.

### Packages

The packages:

| Package | Role |
|---|---|
| `freezer_driver` | `Driver` interface, `DefaultDriver` over the serial port, `FakeDriver` that runs the table with a host clock, the recipe builder, and `ShotRunner`, which loads, fires and polls a shot with no ROS |
| `freezer_msgs` | the `Shoot` action |
| `freezer_node` | the action server, parameters for the serial port, `use_fake` and the default durations |
| `freezer_mcu` | PlatformIO project for the Nano, not built by colcon |
| `framed_serial` | the framed protocol, as the submodule `modules/framed-serial` |

## Testing Without the Board

StepIt Freezer must run without the board, so that the node, the action and the recipes can be developed and tested on any computer.

### The Fake Driver

`FakeDriver` implements `Driver` and plays the part of the firmware:

- **It validates tables with the same rules** as the firmware, see [What the Firmware Rejects](#what-the-firmware-rejects), and answers with the same errors.
- **It runs the table on a clock it is given**, as `FakeMotor` computes from the `rclcpp::Time` it receives. Tests drive the clock by hand and never sleep: a shot of 1.2 s takes no time to test.
- **It records the timeline**, every pattern and the time it was latched, so a test can assert "camera 3 focused at 0 ms, shutter at 100 ms, flash at 200 ms".
- **It answers as the controller would**, the `ShotResponse` at the start and, for Idea 6, `ShotFinished` at the end, or "running" and "done" to a status query.
- **It can be told to fail**: never send `ShotFinished`, reset in the middle of a shot, refuse a table, or report a step that ran late. These are the paths that are hard to provoke with the real board, and the ones the host code must get right.

The node chooses the fake with a `use_fake` parameter. It is `true` by default, so the project runs without hardware.
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

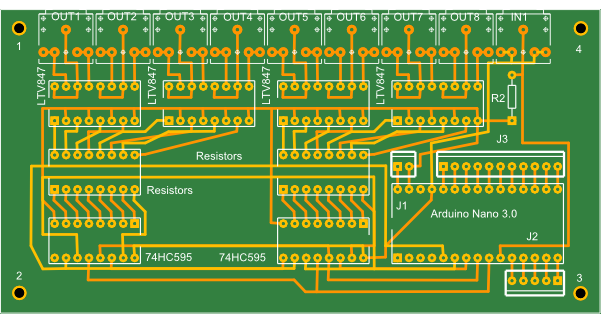
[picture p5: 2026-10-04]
docs/hardware/FreezerPCB.png

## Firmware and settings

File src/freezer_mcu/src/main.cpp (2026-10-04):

// Copyright 2026 Giovanni Remigi
//
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
//    * Redistributions of source code must retain the above copyright
//      notice, this list of conditions and the following disclaimer.
//
//    * Redistributions in binary form must reproduce the above copyright
//      notice, this list of conditions and the following disclaimer in the
//      documentation and/or other materials provided with the distribution.
//
//    * Neither the name of the Giovanni Remigi nor the names of its
//      contributors may be used to endorse or promote products derived from
//      this software without specific prior written permission.
//
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
#include "SerialPort.h"
#include "DataBuffer.h"
#include "Sequencer.h"

// Shift register connections, as routed on the Freezer board. The pin labels
// of docs/hardware/CircuitSchema.png are wrong; these are the ones of the PCB.
constexpr byte OVERRIDING_CLEAR_PIN = 2;  // MR of the 74HC595, low active.
constexpr byte CLOCK_PIN = 3;             // SH_CP of the 74HC595.
constexpr byte DATA_PIN = 4;              // DS of the 74HC595.
constexpr byte OUTPUT_ENABLED_PIN = 5;    // OE of the 74HC595, low active.
constexpr byte LATCH_PIN = 6;             // ST_CP of the 74HC595.

// IN1, the remote trigger: high while it is pressed, pulled down by R2. It
// fires the loaded table, unless a shot is running or no table is loaded.
constexpr byte TRIGGER_PIN = 7;
// How long IN1 must stay at a level before the level counts: a button
// bounces when pressed and when released, and each bounce would fire a shot.
constexpr unsigned long TRIGGER_DEBOUNCE_MS = 20;

constexpr char NAME[] = "FREEZER";

constexpr byte VERSION_MAJOR = 2;
constexpr byte VERSION_MINOR = 0;
constexpr byte VERSION_PATCH = 0;

// Limits of a sequence, reported to the host at the handshake. The host is
// expected to reject a sequence beyond them before sending it.
using sequencer::MAX_DURATION_US;
using sequencer::MAX_STEPS;
using sequencer::MIN_HOLD_US;

constexpr byte STATUS_CMD = 0x75;         // Request the state of the controller and of the last shot.
constexpr byte INFO_CMD = 0x76;           // Request controller info for connection handshaking.
constexpr byte ECHO_CMD = 0x79;           // Return the given bytes, for debugging.
constexpr byte LOAD_SEQUENCE_CMD = 0x7B;  // Store a table of steps, to be fired by SHOOT_CMD.
constexpr byte SHOOT_CMD = 0x7C;          // Fire the loaded table.
constexpr byte SET_OUTPUTS_CMD = 0x77;    // Switch outputs on or off, outside a shot.
constexpr byte STOP_CMD = 0x78;           // End the running shot and switch every output off.

constexpr byte STEP_SIZE = 7;  // Type, outputs and hold, in bytes.
constexpr byte SET_AND_HOLD_STEP = 0x00;

constexpr byte SUCCESS_MSG = 0x11;
constexpr byte ERROR_MSG = 0x12;

// Reasons following an error message.
constexpr byte MALFORMED_ERR = 0x01;      // Unknown command id or wrong payload length.
constexpr byte INVALID_TABLE_ERR = 0x02;  // The table breaks a rule of the controller.
constexpr byte BUSY_ERR = 0x03;           // A shot is running.
constexpr byte NO_TABLE_ERR = 0x04;       // Shoot before any table is loaded.

SerialPort serialPort{ 200, 200 };

DataBuffer responseBuffer{ 200 };

/**
 * Switch every optocoupler off: no camera focuses or shoots and no flash
 * fires. The outputs are disabled while the registers are cleared, so that
 * whatever the 74HC595 held at power on never reaches a camera.
 */
void clearOutputs()
{
  digitalWrite(OUTPUT_ENABLED_PIN, HIGH);
  digitalWrite(LATCH_PIN, LOW);
  digitalWrite(OVERRIDING_CLEAR_PIN, LOW);  // Clear the shift stage.
  digitalWrite(LATCH_PIN, HIGH);            // Copy the zeros to the outputs.
  digitalWrite(LATCH_PIN, LOW);
  digitalWrite(OVERRIDING_CLEAR_PIN, HIGH);
  digitalWrite(OUTPUT_ENABLED_PIN, LOW);
}

/** Send an error response with its reason. */
void returnCommandError(byte reason)
{
  responseBuffer.addByte(ERROR_MSG, BufferPosition::Tail);
  responseBuffer.addByte(reason, BufferPosition::Tail);
  serialPort.write(&responseBuffer);
}

/**
 * Send information about the software installed on Arduino to help the client
 * identify the correct port where Arduino is connected, together with the
 * limits of a sequence.
 *
 * The response carries the limits before the name so that the name is the
 * remaining bytes of the packet:
 *
 *   status           - 1 byte
 *   version          - 3 bytes: major, minor and patch
 *   max steps        - 1 byte
 *   min hold         - 4 bytes, in µs
 *   max duration     - 4 bytes, in µs
 *   name             - the remaining bytes, in ASCII
 */
void returnControllerInfo()
{
  responseBuffer.addByte(SUCCESS_MSG, BufferPosition::Tail);
  responseBuffer.addByte(VERSION_MAJOR, BufferPosition::Tail);
  responseBuffer.addByte(VERSION_MINOR, BufferPosition::Tail);
  responseBuffer.addByte(VERSION_PATCH, BufferPosition::Tail);
  responseBuffer.addByte(MAX_STEPS, BufferPosition::Tail);
  responseBuffer.addLong(MIN_HOLD_US, BufferPosition::Tail);
  responseBuffer.addLong(MAX_DURATION_US, BufferPosition::Tail);
  for (int i = 0; NAME[i] != '\0'; i++)
  {
    responseBuffer.addByte(NAME[i], BufferPosition::Tail);
  }
  serialPort.write(&responseBuffer);
}

/**
 * Echo back the given bytes to test the serial communication.
 * @param cmd The bytes to echo.
 */
void echoCommand(DataBuffer* cmd)
{
  responseBuffer.addByte(SUCCESS_MSG, BufferPosition::Tail);
  while (cmd->getSize() > 0)
  {
    responseBuffer.addByte(cmd->removeByte(BufferPosition::Head), BufferPosition::Tail);
  }
  serialPort.write(&responseBuffer);
}

/**
 * Store a table of steps, to be fired by SHOOT_CMD. The payload is the step
 * count, then for each step its type, its outputs and its hold in µs, most
 * significant byte first. The answer is the duration of the table:
 *
 *   status           - 1 byte
 *   duration         - 4 bytes, in µs
 *
 * The table is checked whole before it replaces the loaded one, so that a
 * rejected table leaves the loaded one as it was. The rules are the host's:
 * the last step must switch every output off, so that a camera is never left
 * with its shutter held.
 * @param cmd The command data.
 */
void loadSequenceCommand(DataBuffer* cmd)
{
  if (cmd->getSize() < 1)
  {
    returnCommandError(MALFORMED_ERR);
    return;
  }
  if (sequencer::status().running)
  {
    returnCommandError(BUSY_ERR);
    return;
  }

  const byte count = cmd->removeByte(BufferPosition::Head);
  if (cmd->getSize() != count * STEP_SIZE)
  {
    returnCommandError(MALFORMED_ERR);
    return;
  }
  if (count == 0 || count > MAX_STEPS)
  {
    returnCommandError(INVALID_TABLE_ERR);
    return;
  }

  sequencer::Step steps[MAX_STEPS];
  uint32_t duration = 0;
  bool valid = true;
  for (byte i = 0; i < count; i++)
  {
    byte bytes[STEP_SIZE];
    for (byte j = 0; j < STEP_SIZE; j++)
    {
      bytes[j] = cmd->removeByte(BufferPosition::Head);
    }
    steps[i].outputs = (static_cast<uint16_t>(bytes[1]) << 8) | bytes[2];
    steps[i].holdUs = (static_cast<uint32_t>(bytes[3]) << 24) | (static_cast<uint32_t>(bytes[4]) << 16) |
                      (static_cast<uint32_t>(bytes[5]) << 8) | bytes[6];

    // Compare each hold before adding it, so that the sum cannot overflow.
    if (bytes[0] != SET_AND_HOLD_STEP || steps[i].holdUs < MIN_HOLD_US || steps[i].holdUs > MAX_DURATION_US)
    {
      valid = false;
    }
    else
    {
      duration += steps[i].holdUs;
    }
  }
  if (!valid || duration > MAX_DURATION_US || steps[count - 1].outputs != 0)
  {
    returnCommandError(INVALID_TABLE_ERR);
    return;
  }

  sequencer::load(steps, count, duration);
  responseBuffer.addByte(SUCCESS_MSG, BufferPosition::Tail);
  responseBuffer.addLong(duration, BufferPosition::Tail);
  serialPort.write(&responseBuffer);
}

/**
 * Fire the loaded table. The answer is sent once the first pattern is
 * latched:
 *
 *   status           - 1 byte
 *   shot id          - 2 bytes
 *   duration         - 4 bytes, in µs
 *
 * @param cmd The command data.
 */
void shootCommand(DataBuffer* cmd)
{
  if (cmd->getSize() != 0)
  {
    returnCommandError(MALFORMED_ERR);
    return;
  }
  const sequencer::Status status = sequencer::status();
  if (status.running)
  {
    returnCommandError(BUSY_ERR);
    return;
  }
  if (!status.loaded)
  {
    returnCommandError(NO_TABLE_ERR);
    return;
  }

  const uint16_t shotId = sequencer::start();
  responseBuffer.addByte(SUCCESS_MSG, BufferPosition::Tail);
  responseBuffer.addInt(shotId, BufferPosition::Tail);
  responseBuffer.addLong(sequencer::duration(), BufferPosition::Tail);
  serialPort.write(&responseBuffer);
}

/**
 * Send the state of the controller and of the last shot. A shot is over for
 * the host when the controller is idle and the last shot id is the one Shoot
 * returned.
 *
 *   status           - 1 byte
 *   state            - 1 byte: 0 idle, 1 running
 *   last shot id     - 2 bytes, 0 when none since power on
 *   step             - 1 byte, the step running
 *   elapsed          - 4 bytes, in µs since the start of the shot
 *   worst lateness   - 4 bytes, in µs, of the last shot
 *
 * @param cmd The command data.
 */
void statusCommand(DataBuffer* cmd)
{
  if (cmd->getSize() != 0)
  {
    returnCommandError(MALFORMED_ERR);
    return;
  }
  const sequencer::Status status = sequencer::status();
  responseBuffer.addByte(SUCCESS_MSG, BufferPosition::Tail);
  responseBuffer.addByte(status.running ? 1 : 0, BufferPosition::Tail);
  responseBuffer.addInt(status.lastShotId, BufferPosition::Tail);
  responseBuffer.addByte(status.step, BufferPosition::Tail);
  responseBuffer.addLong(status.elapsedUs, BufferPosition::Tail);
  responseBuffer.addLong(status.worstLatenessUs, BufferPosition::Tail);
  serialPort.write(&responseBuffer);
}

/**
 * Latch a pattern on the outputs, e.g. to switch the lights on or off, where
 * it stays until the next one, a shot or STOP_CMD. The payload is the 16
 * outputs, 2 bytes. Refused while a shot runs: the shot owns the outputs, and
 * only STOP_CMD ends it.
 * @param cmd The command data.
 */
void setOutputsCommand(DataBuffer* cmd)
{
  if (cmd->getSize() != 2)
  {
    returnCommandError(MALFORMED_ERR);
    return;
  }
  if (!sequencer::setOutputs(cmd->removeInt(BufferPosition::Head)))
  {
    returnCommandError(BUSY_ERR);
    return;
  }
  responseBuffer.addByte(SUCCESS_MSG, BufferPosition::Tail);
  serialPort.write(&responseBuffer);
}

/**
 * End the running shot where it is, if any, and switch every output off.
 * Always accepted: it is the one command a shot gives way to. The shot keeps
 * its id, and the controller reads idle.
 * @param cmd The command data.
 */
void stopCommand(DataBuffer* cmd)
{
  if (cmd->getSize() != 0)
  {
    returnCommandError(MALFORMED_ERR);
    return;
  }
  sequencer::stop();
  responseBuffer.addByte(SUCCESS_MSG, BufferPosition::Tail);
  serialPort.write(&responseBuffer);
}

/**
 * Fire the loaded table when IN1 is pressed, unless a shot is running or no
 * table is loaded. A level counts once it has held for TRIGGER_DEBOUNCE_MS,
 * and only a press fires: holding the button fires once.
 */
void updateTrigger()
{
  static bool reading = false;  // The level read last.
  static bool pressed = false;  // The level that counts.
  static unsigned long changedMs = 0;

  const bool level = digitalRead(TRIGGER_PIN) == HIGH;
  const unsigned long now = millis();
  if (level != reading)
  {
    reading = level;
    changedMs = now;
    return;
  }
  if (level == pressed || now - changedMs < TRIGGER_DEBOUNCE_MS)
  {
    return;
  }
  pressed = level;
  if (!pressed)
  {
    return;
  }
  const sequencer::Status status = sequencer::status();
  if (!status.running && status.loaded)
  {
    sequencer::start();
  }
}

/**
 * Decode the input command and execute the requested action.
 * @param cmd The the command data.
 */
void processBuffer(DataBuffer* cmd)
{
  byte cmdId = cmd->removeByte(BufferPosition::Head);

  if (cmdId == INFO_CMD && cmd->getSize() == 0)
  {
    returnControllerInfo();
  }
  else if (cmdId == ECHO_CMD)
  {
    echoCommand(cmd);
  }
  else if (cmdId == STATUS_CMD)
  {
    statusCommand(cmd);
  }
  else if (cmdId == LOAD_SEQUENCE_CMD)
  {
    loadSequenceCommand(cmd);
  }
  else if (cmdId == SHOOT_CMD)
  {
    shootCommand(cmd);
  }
  else if (cmdId == SET_OUTPUTS_CMD)
  {
    setOutputsCommand(cmd);
  }
  else if (cmdId == STOP_CMD)
  {
    stopCommand(cmd);
  }
  else
  {
    returnCommandError(MALFORMED_ERR);
  }
  cmd->clear();
}

void setup()
{
  pinMode(OUTPUT_ENABLED_PIN, OUTPUT);
  digitalWrite(OUTPUT_ENABLED_PIN, HIGH);
  pinMode(OVERRIDING_CLEAR_PIN, OUTPUT);
  pinMode(CLOCK_PIN, OUTPUT);
  pinMode(DATA_PIN, OUTPUT);
  pinMode(LATCH_PIN, OUTPUT);
  pinMode(TRIGGER_PIN, INPUT);  // Pulled down on the board, by R2.
  digitalWrite(CLOCK_PIN, LOW);
  digitalWrite(DATA_PIN, LOW);
  clearOutputs();
  sequencer::init();

  serialPort.init(9600);
  serialPort.setCallback(&processBuffer);
}

void loop()
{
  serialPort.update();  // Read/write serial port data.
  updateTrigger();
}

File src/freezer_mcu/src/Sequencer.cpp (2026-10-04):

// Copyright 2026 Giovanni Remigi
//
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
//    * Redistributions of source code must retain the above copyright
//      notice, this list of conditions and the following disclaimer.
//
//    * Redistributions in binary form must reproduce the above copyright
//      notice, this list of conditions and the following disclaimer in the
//      documentation and/or other materials provided with the distribution.
//
//    * Neither the name of the Giovanni Remigi nor the names of its
//      contributors may be used to endorse or promote products derived from
//      this software without specific prior written permission.
//
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
#include "Sequencer.h"

#include <util/atomic.h>

// The shift registers are on port D, written directly: digitalWrite takes
// about 4 µs a call, and the interrupt must shift 16 bits between two steps
// as short as MIN_HOLD_US. The bits are those of the pins in main.cpp.
constexpr uint8_t CLOCK_BIT = _BV(PD3);  // D3, SH_CP of the 74HC595.
constexpr uint8_t DATA_BIT = _BV(PD4);   // D4, DS of the 74HC595.
constexpr uint8_t LATCH_BIT = _BV(PD6);  // D6, ST_CP of the 74HC595.

namespace sequencer
{
namespace
{
// The loaded table. Written only while not running, read by the interrupt.
uint16_t outputs[MAX_STEPS];
uint32_t holdTicks[MAX_STEPS];
byte count = 0;
uint32_t durationUs = 0;

// The state of the shot, shared with the interrupt.
volatile bool running = false;
volatile byte step = 0;
volatile uint32_t startTicks = 0;
volatile uint32_t targetTicks = 0;  // The end of the current step.
volatile uint32_t worstLatenessTicks = 0;
volatile uint16_t overflows = 0;  // The high word of the time, in ticks.
uint16_t lastShotId = 0;

/**
 * Shift a pattern into the 74HC595, least significant bit first, without
 * latching it: the outputs keep the previous pattern. Bit 0 ends in the last
 * stage of the chain, which drives the shutter of OUT1.
 */
inline void shiftPattern(uint16_t value)
{
  for (byte i = 0; i < 16; i++)
  {
    if (value & 1)
    {
      PORTD |= DATA_BIT;
    }
    else
    {
      PORTD &= ~DATA_BIT;
    }
    PORTD |= CLOCK_BIT;
    PORTD &= ~CLOCK_BIT;
    value >>= 1;
  }
  PORTD &= ~DATA_BIT;
}

/** Copy the shifted pattern to the 16 outputs, all at once. */
inline void latchPattern()
{
  PORTD |= LATCH_BIT;
  PORTD &= ~LATCH_BIT;
}

/**
 * The time in ticks of 0.5 µs, on 32 bits: it wraps after about 35 minutes.
 * Call with interrupts disabled. An overflow that has happened but whose
 * interrupt has not run yet is counted, from its pending flag.
 */
inline uint32_t ticksNow()
{
  const uint16_t low = TCNT1;
  uint16_t high = overflows;
  if ((TIFR1 & _BV(TOV1)) && low < 0x8000)
  {
    high++;
  }
  return (static_cast<uint32_t>(high) << 16) | low;
}

/** Arm the compare-match interrupt for the end of the current step. */
inline void schedule()
{
  // The match fires once per wrap of the counter; runDueBoundaries() ignores
  // the matches that come before the target.
  OCR1A = static_cast<uint16_t>(targetTicks);
}
}  // namespace

/**
 * Handle every boundary that is due: latch the next pattern, or end the shot
 * after the last step. Called by the compare-match interrupt, and by start()
 * after arming it. Call with interrupts disabled.
 *
 * It loops, and checks the time again after arming the next match, because a
 * boundary may be due before the match is armed: a step held for less than
 * the time it takes to shift the next pattern in would otherwise wait for the
 * counter to wrap, 32.8 ms later.
 */
void runDueBoundaries()
{
  while (running)
  {
    const uint32_t now = ticksNow();
    const int32_t lateness = static_cast<int32_t>(now - targetTicks);
    if (lateness < 0)
    {
      return;  // Not due yet, e.g. a match of an earlier wrap of the counter.
    }
    if (static_cast<uint32_t>(lateness) > worstLatenessTicks)
    {
      worstLatenessTicks = lateness;
    }
    if (step + 1 >= count)
    {
      // The end of the last step. Its pattern switched every output off.
      running = false;
      TIMSK1 &= ~_BV(OCIE1A);
      return;
    }
    latchPattern();
    step = step + 1;
    targetTicks = targetTicks + holdTicks[step];
    if (step + 1 < count)
    {
      shiftPattern(outputs[step + 1]);
    }
    schedule();
  }
}

void init()
{
  ATOMIC_BLOCK(ATOMIC_RESTORESTATE)
  {
    TCCR1A = 0;          // Normal mode, OC1A and OC1B disconnected.
    TCCR1B = _BV(CS11);  // Prescaler 8: 0.5 µs a tick at 16 MHz.
    TCNT1 = 0;
    TIFR1 = _BV(TOV1) | _BV(OCF1A);
    TIMSK1 = _BV(TOIE1);  // The compare match is enabled by start().
  }
}

void load(const Step* steps, byte stepCount, uint32_t tableDurationUs)
{
  for (byte i = 0; i < stepCount; i++)
  {
    outputs[i] = steps[i].outputs;
    holdTicks[i] = steps[i].holdUs * 2;
  }
  count = stepCount;
  durationUs = tableDurationUs;
}

bool setOutputs(uint16_t pattern)
{
  ATOMIC_BLOCK(ATOMIC_RESTORESTATE)
  {
    if (running)
    {
      return false;
    }
    shiftPattern(pattern);
    latchPattern();
  }
  return true;
}

void stop()
{
  ATOMIC_BLOCK(ATOMIC_RESTORESTATE)
  {
    // The shift stage may hold the next pattern of the shot: zeros replace it.
    running = false;
    TIMSK1 &= ~_BV(OCIE1A);
    TIFR1 = _BV(OCF1A);
    shiftPattern(0);
    latchPattern();
  }
}

uint32_t duration()
{
  return durationUs;
}

uint16_t start()
{
  lastShotId = lastShotId == 0xFFFF ? 1 : lastShotId + 1;
  ATOMIC_BLOCK(ATOMIC_RESTORESTATE)
  {
    shiftPattern(outputs[0]);
    const uint32_t now = ticksNow();
    latchPattern();
    startTicks = now;
    step = 0;
    targetTicks = now + holdTicks[0];
    worstLatenessTicks = 0;
    running = true;
    if (count > 1)
    {
      shiftPattern(outputs[1]);
    }
    TIFR1 = _BV(OCF1A);  // Drop a match that happened before this shot.
    schedule();
    TIMSK1 |= _BV(OCIE1A);
    runDueBoundaries();  // The end of step 0 may already be due.
  }
  return lastShotId;
}

Status status()
{
  Status result;
  ATOMIC_BLOCK(ATOMIC_RESTORESTATE)
  {
    result.running = running;
    result.step = running ? step : 0;
    result.elapsedUs = running ? (ticksNow() - startTicks) / 2 : 0;
    result.worstLatenessUs = (worstLatenessTicks + 1) / 2;
  }
  result.loaded = count > 0;
  result.lastShotId = lastShotId;
  return result;
}
}  // namespace sequencer

using namespace sequencer;

ISR(TIMER1_OVF_vect)
{
  overflows++;
}

ISR(TIMER1_COMPA_vect)
{
  runDueBoundaries();
}

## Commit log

2026-10-02 Fire cameras and flashes on the Freezer board from ROS2
    Freezer Driver drives the Freezer board, an Arduino Nano with two
    74HC595 shift registers and 16 optocouplers on 8 jacks, from ROS2, with
    the framed, CRC-checked request and response protocol of StepIt Driver.
    - freezer_msgs: the Shoot action and the Step message.
    - freezer_driver: the Driver interface, DefaultDriver over the serial
    port, a FakeDriver on a clock the tests control, the rules of a
    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
2026-10-02 Fire the loaded sequence from the firmware, on Timer1
    Firmware 1.1.0 adds LoadSequence, Shoot and Status, the commands the
    driver already speaks.
    - LoadSequence checks the whole table with the rules of the host before
    it replaces the loaded one, and answers with its CRC-16 and its
    duration.
    - Shoot latches the first pattern and answers with the shot id.
    - Status reports the state, the step, the elapsed time and the worst
    lateness of the last shot.
    Timer1 keeps the time at 0.5 us a tick, extended to 32 bits by its
    overflows. Each step ends at an absolute time, and the compare-match
    interrupt latches the pattern shifted in during the step before, so the
    16 outputs change together and l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
    [Sequencer.cpp, main.cpp]
2026-10-02 Run the CI of StepIt Driver: build, test, format and lint
    Three workflows, as in StepIt Driver, with their badges in the README:
    - industrial_ci builds the packages and runs their tests in ROS2 Jazzy.
    Its checkout does not fetch the submodules, so it builds
    framed-serial and serial from freezer.repos.
    - Format runs the pre-commit hooks on every file.
    - ROS Lint runs ament_copyright, ament_lint_cmake and ament_cpplint on
    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
2026-10-02 Do not expect the first feedback of a shot to arrive
    rclcpp_action drops the feedback published before the client has
    processed the acceptance of its goal, so a client may miss LOADING, and
    on a slow machine the first RUNNING too: the industrial_ci run of the
    push failed on it. The test now checks only that the feedback received
    is in order, and the README and the brainstorm say a client must rely on
    the result, not on the feedback, to know a shot has started.
    [test_freezer_node.cpp]
2026-10-02 Run a shot in ShotRunner, with no ROS, and test it on a fake clock
    The node did everything of a shot itself: load the sequence when it
    changed, fire it, retry once when the controller lost it, poll until the
    end, give up at the deadline. Its tests went through a real action
    client, with threads, DDS and real time, and failed on CI when the
    client missed the first feedback.
    ShotRunner, in freezer_driver, now runs a shot on a Driver and knows
    nothing of ROS. Time comes in as a clock and a sleep, so its tests run a
    shot on the clock of a FakeDriver, instantly and exactly: the callbacks,
    a sequence loaded once, a cancel, a refused table, a shot that never
    ends, and a reset during and between sh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
    [test_freezer_node.cpp]
2026-10-04 Revise the protocol: lights, stop, the trigger, no checksum, no watchdog
    SetOutputs switches outputs outside a shot and Stop ends one; IN1 fires the
    loaded table unless a shot runs or none is loaded. The table keeps being
    loaded, for IN1. The checksum of Shoot and the watchdog are dropped: version
    2.0.0. Design only, not implemented yet.
2026-10-04 Implement protocol 2.0.0: lights, stop and the trigger, without the checksum
    The firmware answers SetOutputs, which latches a pattern outside a shot and is
    refused as busy during one, and Stop, which ends a shot where it is and
    switches every output off. IN1 fires the loaded table, unless a shot is
    running or none is loaded, once its level has held for 20 ms. Shoot carries no
    checksum anymore, nor do LoadSequence and Status: ShotRunner remembers the
    sequence it loaded instead.
    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
2026-10-04 Add the board page, the architecture document and the board's hardware files
    The board page, in web: React and TypeScript, built with Vite and pnpm. It
    fires the commands through rosbridge and draws the timing of each shot, a row
    per line, from the shot's table, which the controller runs exactly. The
    launch file starts its rosbridge, on port 9092, and serves it, on port 8092.
    For it, the node publishes outputs and shots, each keeping its last message
    for a late subscriber: rosbridge passes a new client only the first kept
    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
    [Freezer.fzz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]
2026-10-05 Disable Press IN1 when the node drives the board
    The button calls fake/press_trigger, which the node creates only with the
    fake controller, so against the board it failed with no explanation. The
    page now reads the parameter use_fake, as it reads the sequence names, since
    it has no rosapi to list the services, and disables the button unless the
    controller is fake. Its tooltip says to close the IN1 jack on the board.
2026-10-05 Rename Freezer Driver to StepIt Freezer
    The repository is renamed from freezer-driver to stepit-freezer, and the project from Freezer Driver to StepIt Freezer, in the family of the StepIt projects, named stepit-<device or tool>. The docume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
2026-10-06 Drop the history of the board's design from its README
2026-10-07 Connect the controller again when it is back
    The node connected once, at start: a Nano missing then, as a Raspberry Pi
    sometimes misses it at boot, or unplugged later, needed a restart. Now a
    thread tries to connect every reconnect_period, 2 s, while there is no
    controller, and watch() lets the controller go after three status queries
    that fail in a row. The fake controller can be unplugged, for the tests.
    [test_freezer_node.cpp]
2026-10-09 Keep every status in the test of an unplugged controller
    After an unplug, the node tells that the controller stopped answering,
    then a failed try to connect again may replace the reason with its own
    error at once: the test read the last status only, and failed on CI.
    [test_freezer_node.cpp]
